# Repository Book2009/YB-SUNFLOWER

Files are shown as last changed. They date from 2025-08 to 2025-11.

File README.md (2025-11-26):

# Welcome to Team Sunflower's Repository 🌻✨
### ***We Are Team Sunflower From Thailand***

<p align="center">
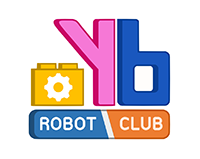
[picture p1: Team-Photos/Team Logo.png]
  
</p>

<p align="center">
  By Yothinburana School
</p>

---

# Content

`3DModels` – This folder includes the 3D design files of the vehicle. These files show the mechanical structure, dimensions, and how each part fits together.

`FlowChart` – This folder contains flowcharts that illustrate the robot’s control logic and how it processes sensor inputs during missions.

`Others` – This folder includes supporting materials such as the work schedule, and robot assembly GIFs.

`Program` – This folder includes all source codes used in the WRO 2025 Future Engineers category.

`Robot-Photos` – This folder contains photos of the vehicle from multiple perspectives.

`Schemes` – This folder contains wiring and electrical schematic diagrams. These diagrams show all components in the robot and how they are connected together.

`Team-Photos` – This folder includes photos of the team participating in the WRO 2025 Future Engineers Category.

`Videos` – This folder contains YouTube links that demonstrate how the robot operates to complete both missions.

`Readme` – This README contains 3 parts:
  - [About Us](#part-1-about-us)
  - [Mechanical Design](#part-2-mechanical-design)
  - [Obstacle Management](#part-3-obstacle-management)

---

# **Part 1: About Us**

## **This is our team.**
Our team name, **Sunflower**, carries a meaningful story. In Thai, the word “Sunflower” means *ดอกทานตะวัน*, which is directly connected to the name of one of our seniors. Since 2023, he has inspired us to join the Future Engineers competition—always supporting us and giving guidance from outside the team. To honor the role he played in motivating us, we included **“Sunflower”** in our team name.

This year is even more special, because in the national competition round, he was finally able to compete together with us as part of the team. Unfortunately, he is unable to join the international round of the competition.

<hr>

### **Team History**
We are **Sunflower**, a team from Bangkok, Thailand. We are part of the **YB-Robot Club** from Yothinburana School, with our mentor **Punnapon Tanasnitikul**.  
Our club website: https://ybrobot.club/

The club was established in 2009 under the original name **“YB Dream Team.”** Last year, we also participated in **WRO 2024**, which took place in Türkiye.

`2010 — First International Round Achievement`  
Our first time competing in the WRO international round, where our team achieved **3rd place (Second Runner-Up)**.  
<p align="center">
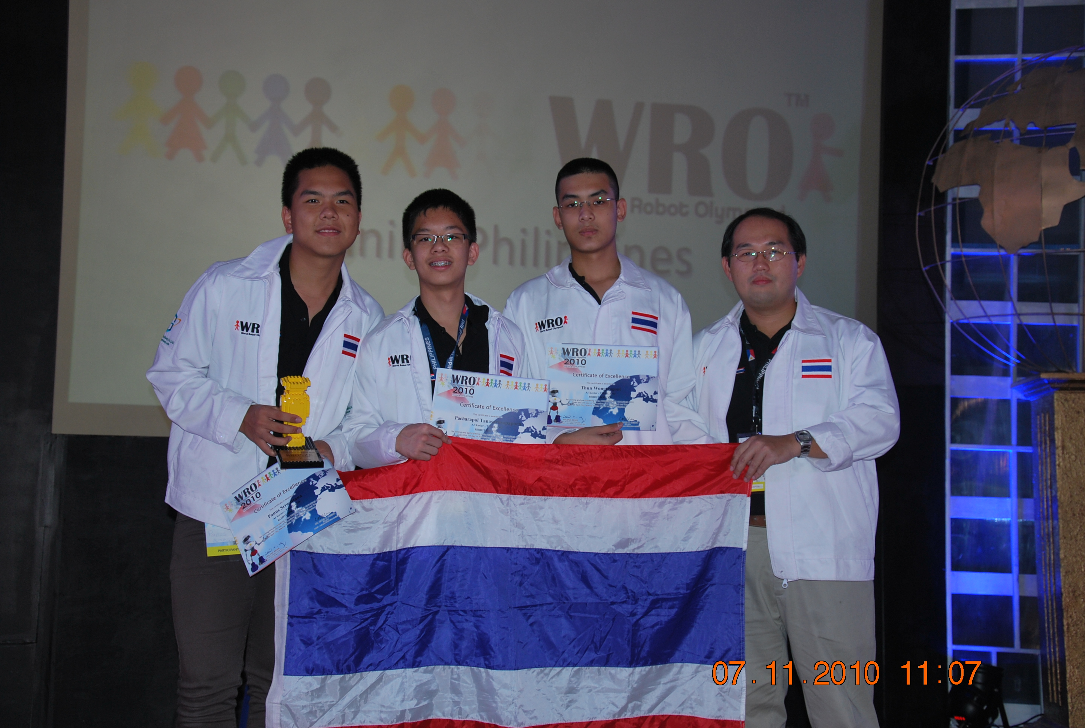
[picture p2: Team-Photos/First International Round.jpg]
  
</p>

`2011 — Second International Round Achievement`  
In our second participation in the WRO international round, our team won **1st place (Champion)**.  
<p align="center">
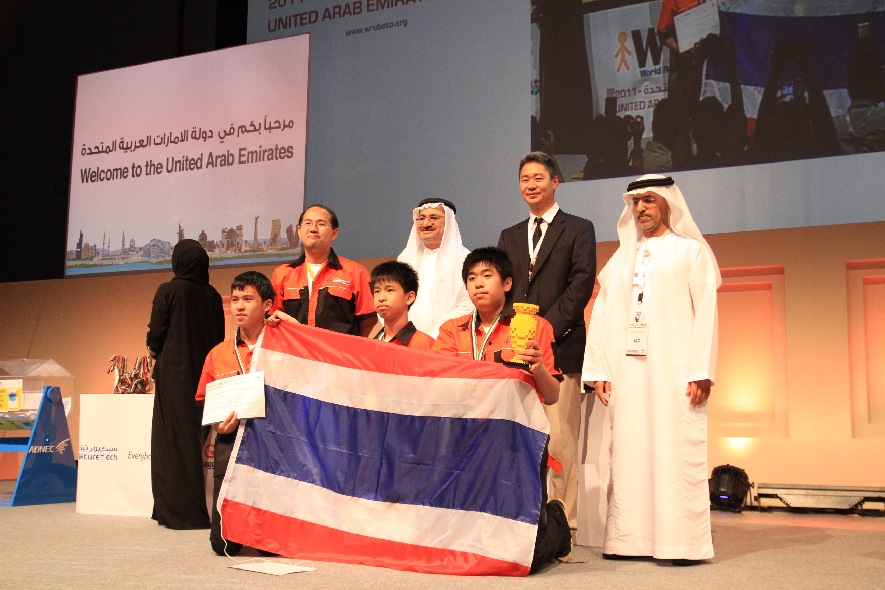
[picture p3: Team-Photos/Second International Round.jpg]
  
</p>

`Latest International Round Result`  
Among our many years of participation, the most recent highlighted result is from **2024**, where we placed **13th** in the international round.  
<p align="center">
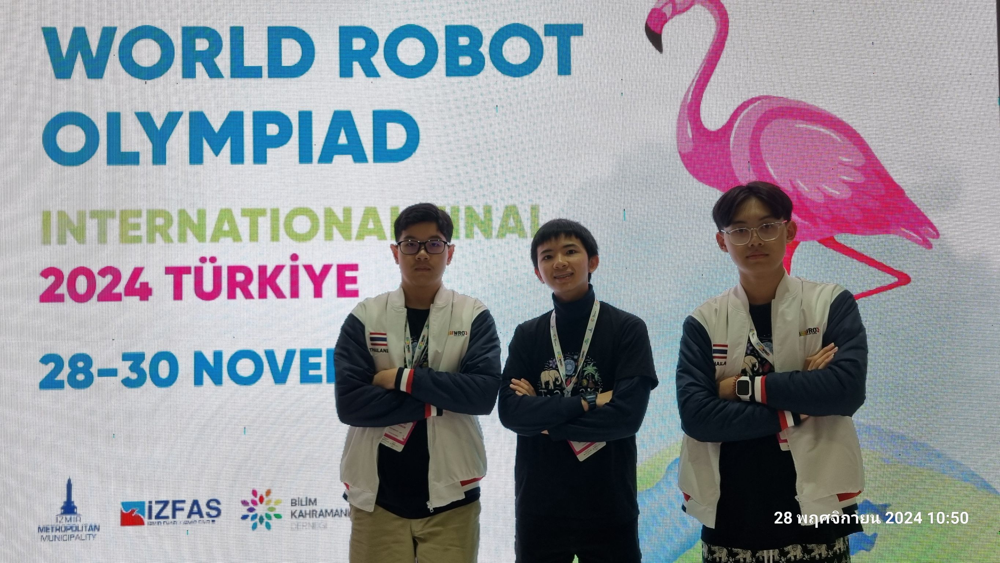
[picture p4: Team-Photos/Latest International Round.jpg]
  
</p>

Currently in 2025, we are part of the **YB Robot Team**. Our senior helped bring this team name to global recognition, and we aim to continue the legacy and make them proud.

<hr>

### **Our Team**
Our team consists of two close friends, **Thanyawut Krittikanon** and **Pawit Nateenantasawasd**. We have known each other since 2021 and formed a strong bond through years of working together in our school’s robotics club. Throughout high school, we joined many robotics competitions, shared knowledge, and improved our skills side by side. These shared experiences have shaped how well we collaborate today.

Over the past two years, we joined the **Future Engineers** category twice. Reaching the international round was already an honor, and although we finished in **8th** and **13th** place, those experiences taught us that enthusiasm alone is not enough—we needed stronger strategies, cleaner designs, and better execution.

This year, we return with greater confidence and far more experience. We refined our workflow, strengthened our engineering approach, and fixed the mistakes from previous years. Coming back to this competition motivates us to do our best, and we aim to deliver results that make everyone proud.

<p align="center">
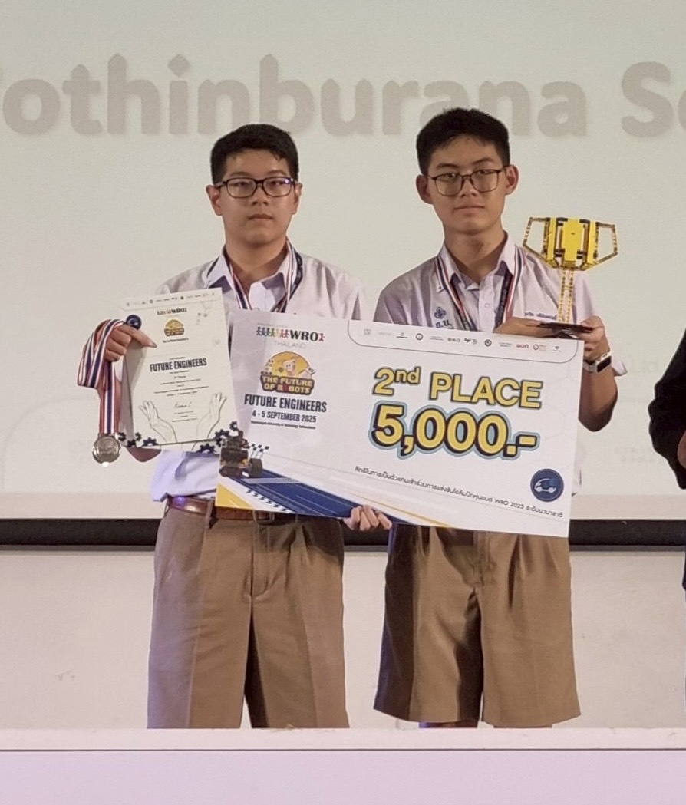
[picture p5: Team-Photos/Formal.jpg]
    
</p>
<hr>

There are two members on our team, each focused and dedicated to their responsibilities:

### **1. Thanyawut Krittikanon – Team Coordinator, Robot Designer & Document Designer**
<p align="center">
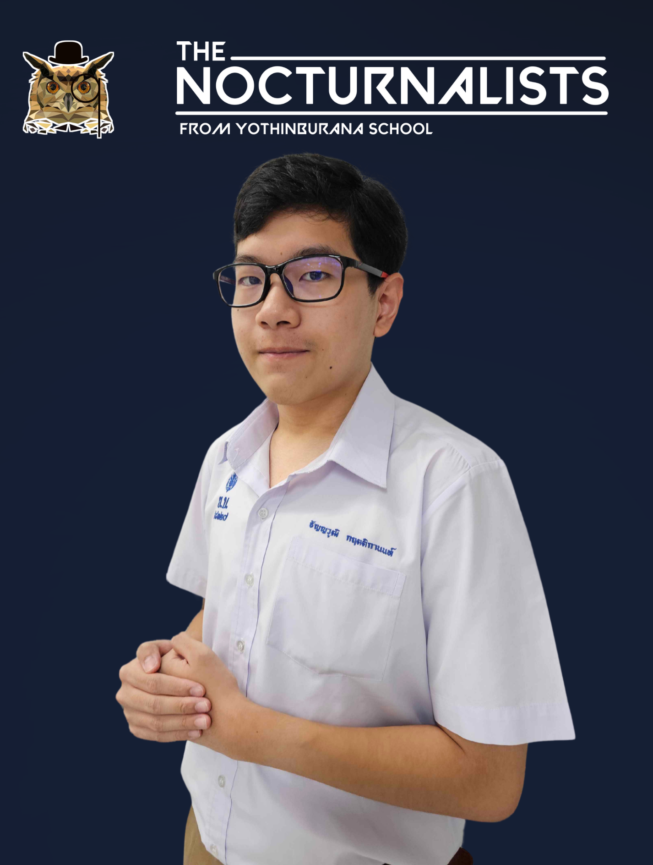
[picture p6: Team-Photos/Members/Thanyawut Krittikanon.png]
    
</p>

Thanyawut is responsible for team coordination, robot design, and documentation. His background in both robotics and programming helps him organize the team’s workflow and ensure that every process is clearly recorded and accurately presented.  

As the robot designer, he works on mechanical concepts and 3D modeling, turning ideas into practical and efficient designs. As the document designer, he structures the reports, diagrams, and technical explanations, ensuring that all information is clear, professional, and aligned with the competition requirements.

His creativity, attention to detail, and ability to combine engineering with presentation make him a key part of the team’s success.

---

### **2. Pawit Nateenantasawasd – Programmer**
<p align="center">
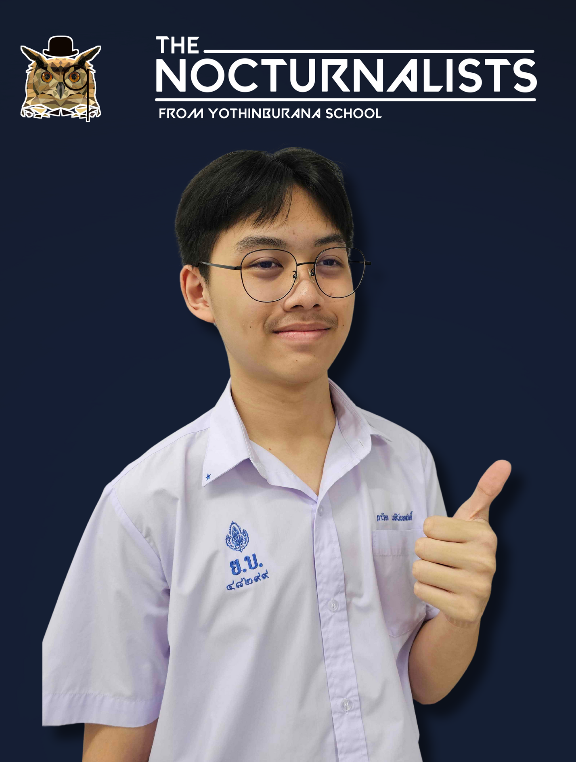
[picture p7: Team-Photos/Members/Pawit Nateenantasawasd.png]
    
</p>

Pawit is our lead programmer, specializing in languages such as **C++, C, Python, MicroPython, and HTML**.  
Quiet and focused, he excels at solving complex programming challenges with precision. His ability to stay concentrated allows him to implement highly detailed control logic and ensure that our robot operates smoothly and reliably. His dedication plays a key role in keeping the entire system functioning.

<hr>

### **Our Vision and Goal**

We aim to create a robot that operates similarly to a self-driving car, with the long-term dream of integrating our technology into real vehicles. This competition is an important step toward our future goals of contributing to our country and developing innovative solutions.  

Through participating in this competition, we have gained valuable skills such as collaboration, creativity, and forward thinking. We also hoped to meet new friends and exchange knowledge with teams from around the world.  

Furthermore, we plan to use the experience we gain from this tournament to improve ourselves and to guide and mentor our juniors at school, helping them grow just as we have.

<hr>

# **Part 2: MECHANICAL DESIGN**

## Robot Design Overview



The robot is primarily composed of custom 3D-printed components, forming a lightweight yet durable structure for all major systems. Each part is designed to fit its specific purpose and connects cleanly with others, creating a modular framework that can be easily upgraded or adjusted as our design evolves.

The overall layout supports the placement of motors, electronics, the battery, and key sensors while maintaining neat cable routing and good airflow. With the flexibility of 3D printing, we optimized the internal spacing, balance, and part placement to improve stability and functionality.

To ensure accurate obstacle detection, the LiDAR sensor is mounted in an unobstructed position (below 10 cm from the ground), giving it a clear field of view throughout the missions. This approach minimizes weight, simplifies assembly, and allows for quick replacement or upgrading of components.

[All 3D-printable models can be found here.](https://github.com/Book2009/YB-SUNFLOWER/tree/main/3DModels)

<hr>

### Main Base

<table align="center">
  <tr>
    <td align="center">
      
      <p><a href="https://github.com/Book2009/YB-SUNFLOWER/blob/main/3DModels/Main%20Base.stl" target="_blank">Click here to view the 3D model.</a></p>
    </td>
  </tr>
</table>

The Main Base serves as the robot’s primary structural layer. The Raspberry Pi 5 is mounted on this level to keep the board low, since an extension board sits on top of it; this position prevents unnecessary height, simplifies cable routing, and avoids blocking the camera’s field of view.

This layer provides mounting positions for the **Servo Bracket** and **Motor Mount**, which hold the steering servo and the motors with the differential gear mechanism. These mounting locations are centered to maintain proper alignment and balanced weight distribution. 

The Main Base also includes dedicated connection points for attaching the next structural layer, allowing the upper components to stack securely. 

<hr>

### Support Base 1

<table align="center">
  <tr>
    <td align="center">
        

  <p><a href="https://github.com/Book2009/YB-SUNFLOWER/blob/main/3DModels/Support%20Base%201.stl" target="_blank">Click here to view 3D model.</a></p>
  </tr>
</table>

Support Base 1 is the structural layer positioned above the Main Base. It provides mounting locations for the gyro sensor and the Lidar Mount, forming the platform where these components are securely attached. The rear section includes a recessed cutout that allows the power cable to pass through to the Raspberry Pi 5 without interference.

This part also features countersunk mounting holes, preventing the screw heads or nuts from protruding. This ensures that the wiring and the steering mechanism beneath the layer have sufficient clearance and do not come into contact with any hardware. Support Base 1 establishes a clean separation between the lower mechanical systems and the upper sensing components.

<hr>

### Support Base 2.1

<table align="center">
  <tr>
    <td align="center">
      

  <p><a href="https://github.com/Book2009/YB-SUNFLOWER/blob/main/3DModels/Support%20Base%202.1.stl" target="_blank">Click here to view 3D model.</a></p>
  </tr>
</table>

Support Base 2.1 is an upper structural layer used to mount the motor driver, touch sensor, and step-down module. The touch sensor and step-down are installed on angled surfaces, allowing the sensor to remain easily accessible even after **Support Base 2.2** is mounted above this layer, while also preventing the solder joints of the step-down module from contacting the printed part.

The angled geometry also improves printability and durability, as fully vertical mounts would be harder to print and more prone to breaking. A cable-routing slot is integrated to organize power wires and keep them clear of surrounding components. The part also includes mounting holes designed specifically for attaching the next structural layer.

This layer provides an efficient layout for key electronic modules while forming the connection point for the robot’s multi-layer assembly.

<hr>

### Support Base 2.2

<table align="center">
  <tr>
    <td align="center">
      

  <p><a href="https://github.com/Book2009/YB-SUNFLOWER/blob/main/3DModels/Support%20Base%202.2.stl" target="_blank">Click here to view 3D model.</a></p>
  </tr>
</table>

Support Base 2.2 is the structural layer installed above Support Base 2.1. It provides mounting locations for the step-down module that supplies power to the motor driver, as well as attachment points for the camera positioning mechanism, the camera shield plate, and the switch box.

The central recessed opening is designed specifically to allow the step-down module to sit lower in the structure, preventing its solder joints from contacting the printed surface and ensuring safe electrical clearance. The surrounding frame maintains rigidity while keeping all mounting points properly aligned with the lower layer.

This layer organizes several functional electronic and camera-related components while maintaining secure integration within the robot’s multi-layer mechanical structure.

<hr>

### Camera Shield Plate

<table align="center">
  <tr>
    <td align="center">
        

  <p><a href="https://github.com/Book2009/YB-SUNFLOWER/blob/main/3DModels/Camera%20Shield%20Plate.stl" target="_blank">Click here to view 3D model.</a></p>
  </tr>
</table>

The Camera Shield Plate is designed to prevent internal wires and electronic components from entering the camera’s field of view. Although software cropping can remove unwanted areas, this physical shield provides additional reliability—especially important when competing internationally, where lighting conditions and arena environments may differ from our testing setup. Since a 3D printer cannot be brought to the competition venue, the shield serves as a precaution against unexpected visual obstructions.

The plate is mounted using shared screw points with the lower support layers, forming an integrated structure. Its hood-like geometry blocks the camera’s downward and forward viewing angles, while the recessed underside creates extra clearance for the components beneath it, ensuring the shield sits correctly without interfering with wiring or modules.

<hr>

### Camera Positioning Mechanism

<p align="center">

</p>

<table align="center">
  <tr>
    <td align="center">
      Left
      <p><details>
  <summary>Camera Height Adjustment Link</summary>

  <p><a href="https://github.com/Book2009/YB-SUNFLOWER/blob/main/3DModels/Camera%20Height%20Adjustment%20Link.stl" target="_blank">Click here to view 3D model.</a></p>

</details></p>
    </td>
    <td align="center">
      Center
      <p><details>
  <summary>Angle Adjustment Link</summary>

  <p><a href="https://github.com/Book2009/YB-SUNFLOWER/blob/main/3DModels/Angle%20Adjustment%20Link.stl" target="_blank">Click here to view 3D model.</a></p>

</details></p>
    </td>
 <td align="center">
      Right
      <p><details>
  <summary>Camera Adjustment Column</summary>

  <p><a href="https://github.com/Book2009/YB-SUNFLOWER/blob/main/3DModels/Camera%20Adjustment%20Column.stl" target="_blank">Click here to view 3D model.</a></p>

</details></p>
    </td>
  </tr>
</table>

The Camera Positioning Mechanism is designed to provide adjustable camera height and angle, allowing the camera to be tuned for varying lighting conditions or different field environments during competition. This adjustability ensures the robot can adapt even when the lighting or arena setup in an international venue differs from our testing conditions.

The mechanism consists of three main components: the Camera Adjustment Column, the Height Adjustment Link, and the Angle Adjustment Link. The vertical slots in the column allow the camera to be raised or lowered, while the pivoting links enable precise angle adjustment. Together, these components form a compact and stable assembly that maintains the camera’s alignment while offering flexible configuration options.

This mechanism allows rapid on-site adjustments without requiring redesign or reprinting of parts.

<hr>

### Servo Bracket

<table align="center">
  <tr>
    <td align="center">
       

  <p><a href="https://github.com/Book2009/YB-SUNFLOWER/blob/main/3DModels/Servo%20Bracket.stl" target="_blank">Click here to view 3D model.</a></p>
  </tr>
</table>

The Servo Bracket is designed to mount a LEGO-compatible steering servo, which normally attaches using Technic pins instead of screws. To support this, the bracket includes integrated cylindrical pegs that function like Technic pins, allowing the servo to snap and lock securely into place.

Its U-shaped structure with side mounting plates provides stability and proper alignment when attached to the Main Base. The geometry positions the servo at the correct height and orientation for the steering mechanism while remaining lightweight and easy to print.

This design enables the LEGO-style servo to integrate seamlessly with the custom 3D-printed chassis.

<hr>

### Ultrasonic Sensor Mount

<table align="center">
  <tr>
    <td align="center">
      

  <p><a href="https://github.com/Book2009/YB-SUNFLOWER/blob/main/3DModels/Ultrasonic%20Sensor%20Mount.stl" target="_blank">Click here to view 3D model.</a></p>
  </tr>
</table>

The Ultrasonic Sensor Mount positions the sensor in a fixed forward-facing orientation. It is attached using the same screws that secure the rear side of the motor driver, allowing the mount to be installed without additional fasteners. Its slim, elongated shape provides the required spacing and keeps the sensor aligned and stable within the chassis.

<hr>

### Lidar Mount

<table align="center">
  <tr>
    <td align="center">
        

  <p><a href="https://github.com/Book2009/YB-SUNFLOWER/blob/main/3DModels/Lidar%20Mount.stl" target="_blank">Click here to view 3D model.</a></p>
  </tr>
</table>

The Lidar Mount holds the LiDAR sensor in its optimal position and is shaped with a recessed center area, allowing it to sit directly above the gyro module without interference. The mounting tabs on both sides secure the plate to the support structure, while the rounded top surface provides a stable platform for the LiDAR to operate with a clear field of view.

<hr>

### Motor Mount

<table align="center">
  <tr>
    <td align="center">
        

  <p><a href="https://github.com/Book2009/YB-SUNFLOWER/blob/main/3DModels/Motor%20Mount.stl" target="_blank">Click here to view 3D model.</a></p>
  </tr>
</table>

The Motor Mount is the only chassis component not produced with a 3D printer. It is made from steel to provide exceptional strength and rigidity for securing the motors. The mount includes threaded holes, allowing screws to be fastened directly without the need for nuts, making the part both compact and easy to assemble.

Although steel is heavier than plastic, the mount’s small size keeps the weight minimal. A plastic version would need to be larger and reinforced to match the required strength, resulting in no real weight advantage. Using steel ensures long-term durability, high resistance to mechanical stress, and a stable foundation for the motor system.

<p align="center">


<hr>

### Gear Adapter

<table align="center">
  <tr>
    <td align="center">
      

  <p><a href="https://github.com/Book2009/YB-SUNFLOWER/blob/main/3DModels/Gear%20Adapter.stl" target="_blank">Click here to view 3D model.</a></p>
  </tr>
</table>

The gear adapter is a custom-designed component that interfaces the GM25 motor with LEGO differential gears. Since the GM25 motor shaft cannot directly engage with LEGO gears, this adapter provides a secure and precise connection. The central bore is dimensioned for a tight press-fit onto the GM25 shaft to prevent slippage during operation, while two side holes accommodate LEGO Technic pins, allowing the adapter to lock seamlessly into the LEGO gear system.

This design enables a robust integration between a non-LEGO motor and LEGO drivetrain components, ensuring smooth, reliable, and efficient power transmission.

<p align="center">
   

<hr>

### Rear Wheel Bearing Mount
<p align="center">

</p>

<table align="center">
  <tr>
    <td align="center">
      Left
      <p><details>
  <summary>Right Bearing Mount</summary>

  <p><a href="https://github.com/Book2009/YB-SUNFLOWER/blob/main/3DModels/Right%20Bearing%20Mount.stl" target="_blank">Click here to view 3D model.</a></p>

</details></p>
    </td>
    <td align="center">
      Center
      <p><details>
  <summary>Middle Bearing Mount</summary>

  <p><a href="https://github.com/Book2009/YB-SUNFLOWER/blob/main/3DModels/Middle%20Bearing%20Mount.stl" target="_blank">Click here to view 3D model.</a></p>

</details></p>
    </td>
 <td align="center">
      Right
      <p><details>
  <summary>Left Bearing Mount</summary>

  <p><a href="https://github.com/Book2009/YB-SUNFLOWER/blob/main/3DModels/Left%20Bearing%20Mount.stl" target="_blank">Click here to view 3D model.</a></p>

</details></p>
    </td>
  </tr>
</table>

The Rear Wheel Bearing Mount is designed to hold standard ball bearings that support the differential output shaft. The inner race of the bearing interfaces with the shaft through a custom sleeve, allowing smooth and low-friction rotation, while the outer race is securely fixed within the mount. This configuration keeps the rear axle properly aligned, prevents bending under load, and avoids the friction that would occur if the shaft were to rotate directly against 3D-printed surfaces.

The bearing mounts are split into left, middle, and right sections to match the spacing and geometry of the drivetrain, functioning similarly to a pillow block bearing while fitting the robot’s compact chassis layout.

<p align="center">


<hr>

### Axle Sleeve Adapter

<p align="center">

</p>

<table align="center">
  <tr>
    <td align="center">
      Left
      <p><details>
  <summary>Right Axle Sleeve Adapter(For Rear Wheel)</summary>

  <p><a href="https://github.com/Book2009/YB-SUNFLOWER/blob/main/3DModels/Right%20Axle%20Sleeve%20Adapter(For%20Rear%20Wheel).stl" target="_blank">Click here to view 3D model.</a></p>

</details></p>
    </td>
    <td align="center">
      Right
      <p><details>
  <summary>Left Axle Sleeve Adapter(For Rear Wheel)</summary>

  <p><a href="https://github.com/Book2009/YB-SUNFLOWER/blob/main/3DModels/Left%20Axle%20Sleeve%20Adapter(For%20Rear%20Wheel).stl" target="_blank">Click here to view 3D model.</a></p>

</details></p>
    </td>
  </tr>
</table>

The Axle Sleeve Adapter is designed to interface the LEGO cross axle with the inner bore of the bearing used in the Rear Wheel Bearing Mount. The cross axle, which transmits rotational power from the differential gear to the rear wheels, does not match the circular geometry of the The Axle Sleeve Adapter is designed to interface the LEGO cross axle with the circular inner bore of the bearing used in the Rear Wheel Bearing Mount. Because the LEGO cross axle does not match the round geometry of the bearing, the adapter includes a cross-shaped internal profile that fits the axle tightly, while the outer surface is machined as a precise cylinder sized for the bearing.

This sleeve prevents the axle from rubbing against printed surfaces, allowing the rear shaft to rotate smoothly through the bearing while remaining properly aligned. By providing a secure and accurate connection between the LEGO drivetrain and the bearing-supported structure, the Axle Sleeve Adapter improves durability, reduces friction, and increases the efficiency of the rear-wheel power transmission system.

<p align="center">


<hr>

### Steering Module
<p align="center">

</p>

<table align="center">
  <tr>
    <td align="center">
      Left
      <p><details>
  <summary>Right Steering Arm</summary>

  <p><a href="https://github.com/Book2009/YB-SUNFLOWER/blob/main/3DModels/Right%20Steering%20Arm.stl" target="_blank">Click here to view 3D model.</a></p>

</details></p>
    </td>
    <td align="center">
      Center
      <p><details>
  <summary>Top Steering Mount</summary>

  <p><a href="https://github.com/Book2009/YB-SUNFLOWER/blob/main/3DModels/Top%20Steering%20Mount.stl" target="_blank">Click here to view 3D model.</a></p>

</details></p>
    </td>
 <td align="center">
      Right
      <p><details>
  <summary>Right Steering Arm</summary>

  <p><a href="https://github.com/Book2009/YB-SUNFLOWER/blob/main/3DModels/Right%20Steering%20Arm.stl" target="_blank">Click here to view 3D model.</a></p>

</details></p>
    </td>
  </tr>
</table>

<table align="center">
  <tr>
    <td align="center">
      Left
      <p><details>
  <summary>Axle Sleeve Adapter(For Front Wheel) x2</summary>

  <p><a href="https://github.com/Book2009/YB-SUNFLOWER/blob/main/3DModels/Axle%20Sleeve%20Adapter(For%20Front%20Wheel)%20x2.stl" target="_blank">Click here to view 3D model.</a></p>

</details></p>
    </td>
    <td align="center">
      Center
      <p><details>
  <summary>Bottom Steering Mount</summary>

  <p><a href="https://github.com/Book2009/YB-SUNFLOWER/blob/main/3DModels/Bottom%20Steering%20Mount.stl" target="_blank">Click here to view 3D model.</a></p>

</details></p>
    </td>
 <td align="center">
      Right
      <p><details>
  <summary>Steering Linkage Arm</summary>

  <p><a href="https://github.com/Book2009/YB-SUNFLOWER/blob/main/3DModels/Steering%20Linkage%20Arm.stl" target="_blank">Click here to view 3D model.</a></p>

</details></p>
    </td>
  </tr>
</table>

- #### **Steering Linkage Arm**
Connected directly to the steering servo, this arm converts the servo’s rotational output into a push–pull motion. This motion is transferred to both steering arms, allowing the front wheels to change direction together. The linkage is dimensioned to provide smooth and precise steering response.

- #### **Top Steering Mount**
The top bracket that holds the steering assembly together. It stabilizes the upper side of the steering arms and ensures they remain aligned during rotation. Together with the bottom mount, it keeps the module rigid while still allowing the arms to pivot freely.

- #### **Bottom Steering Mount**
The lower structural plate of the steering module. Aside from supporting and aligning the steering arms from below, it also includes a dedicated mounting position for the light sensor. This placement allows the sensor to stay close to the ground for accurate line detection while being protected inside the steering assembly.

- #### **Steering Arm (Left & Right)**
These arms connect directly to each front wheel and convert the push–pull input from the linkage into wheel rotation. Each arm includes a dedicated cylindrical pivot point that fits a metal standoff tube, allowing the arm to rotate smoothly with minimal friction.
The geometry is angled inward to approximate Ackermann steering, ensuring correct wheel angles during turns for improved cornering stability and reduced tire scrub.

<p align="center">


The metal tube remains fixed between the Main Base and Support Base 1, acting as a pivot shaft, while the steering arm rotates around it smoothly.

<p align="center">


- #### **Axle Sleeve Adapter(For Front Wheel) x2**
These adapters allow the LEGO cross axle of the front wheels to interface with the circular inner diameter of the bearings mounted inside the steering arms. The inner profile matches the LEGO axle, while the outer profile fits tightly into the bearing. This ensures smooth bearing rotation and stable wheel alignment—just like the system used for the rear wheels.

<hr>

### Bare Robot Frame

- #### **This image shows the robot’s bare frame, illustrating what the structure looks like without any components installed.**

<p align="center">


## Components

- #### **3D Printer**: Bambu Lab X1 Carbon by Bambu Lab
<image src="https://github.com/Book2009/FE-NOC/blob/main/Robot-Photos/Robot%20Parts/3D/3D%20Printer.png" width = "400">
  
The reasons that we use Bambu Lab X1-Carbon 3D printer because this printer is a high-performance 3D printer designed for precision and efficiency. It is equipped with advanced technology and features, making it suitable for professional use as well as hobbyist projects that require high-quality prints.

##### General Specifications

| Specification | Value |
|---|---|
| Build Volume | 256 × 256 × 256 mm³* |
| Nozzle | 0.4 mm Hardened Steel Included |
| Hotend | All-Metal |
| Max Hot End Temperature | 300 ℃ |
| Filament Diameter | 1.75 mm |
| Supported Filament | PLA, PETG, TPU, ABS, ASA, PVA, PET |
| Ideal for | PA, PC, Carbon/Glass Fiber Reinforced Polymer |

##### Build Plate Specifications

| Specification | Value |
|---|---|
| Build Plate Surface | Bambu Textured PEI Plate or Bambu Cool Plate (Pre-installed, Random, Both compatible with Micro Lidar) |
| Max Build Plate Temperature | 110℃@220V, 120℃@110V |

##### Tool Head Specifications

| Specification | Value |
|---|---|
| Max Speed | 500 mm/s |
| Max Acceleration | 20 m/s² |

##### Physical Dimensions

| Specification | Value |
|---|---|
| X1C Dimensions | 389 × 389 × 457 mm³ |
| Package Size (X1C) | 480 × 480 × 535 mm³ |
| Net Weight (X1C) | 14.13 kg |
| Gross Weight (X1C) | 18 kg |
| Package Size (X1C Combo) | 480 × 480 × 590 mm³ |
| Gross Weight (X1C Combo, AMS included) | 22.3 kg |

##### Electrical Requirements

| Specification | Value |
|---|---|
| Voltage | 100-240 VAC |
| Frequency | 50/60 Hz |
| Power Consumption | 1000W@220V, 350W@110V |

<hr>

- #### **Filament** : Acrylonitrile Butadiene Styrene or simply known as ***ABS***
<image src="https://github.com/Book2009/FE-NOC/blob/main/Robot-Photos/Robot%20Parts/3D/ABS%20Filament.png" width = "400">
  
ABS (Acrylonitrile Butadiene Styrene) was selected as the primary material for the robot’s structural components due to its balanced mechanical and thermal properties. Unlike more brittle plastics, ABS provides a unique combination of rigidity and impact resistance, which allows the parts to endure operational stresses without cracking. Its slight flexibility enables the structures to absorb shocks and vibrations while maintaining dimensional stability. Moreover, ABS retains its form and strength across a wide range of operating temperatures, ensuring reliable performance under varying environmental conditions. These properties make ABS particularly suitable for 3D-printed parts, where durability, accuracy, and stability are essential for assembling complex robotic systems.

<hr><br>

### Movement Parts

- #### **Driving motor** : Chihai 25-370K DC 12V (Gear Ratio 1:20)™.
<image src="https://github.com/ThanyawutII/Test2/blob/main/Hf0a6048f4d30411fbd880a854753fdeaF-removebg-preview.png" width = "400"> <image src="https://github.com/ThanyawutII/Test2/blob/main/DeWatermark.ai_1756699222216.jpg" width = "500">

The Chihai 25-370K DC 12V gear motor with a 1:20 reduction ratio was selected as the drive motor for the robot because it offers an effective balance between speed and torque. The high output speed provided by this configuration allows the robot to achieve competitive ground velocity, while the available torque remains sufficient to drive the system reliably under load. The motor operates efficiently within the limits of the designed power system, and its compact size makes it easy to integrate into the chassis without adding unnecessary weight. In addition, the motor is well suited for use with the LEGO differential gear, ensuring smooth power transmission and responsive handling. Overall, this motor was chosen as the optimal trade-off to provide both performance and stability for competition tasks.

##### Electrical Specifications

| Specification | Value |
|---|---|
| Voltage | 12V DC |

##### Mechanical Specifications

| Specification | Value |
|---|---|
| RATIO | 1: 20  |
| no-load current(mA) | ≤600 |
| no-load speed(rpm) | 980  |
| rated torque(Kg.cm) | 2.3 |
| rated torque(N.m) | 0.21  |
| rated speed (rpm) | 780  |
| rated current (A) | ≤2.7 |
| stall current (A) | ≤16.0  |
| length of gearbox(L) | 19.0 |

<hr>

- #### **Motor Drive Gear** : LEGO Technic Gear 28 Tooth
<image src = "https://github.com/ThanyawutII/Test/blob/main/maxresdefault-removebg-preview.png" width = "250">

The 28-tooth motor drive gear was selected because it provides a perfect 1:1 connection with the 28-tooth differential gear, ensuring smooth and direct power transfer from the motor to the drivetrain. By using gears with equal tooth counts, the system avoids unnecessary changes in torque or speed at this stage, maintaining the rated output characteristics of the motor. This choice simplifies the design, reduces potential misalignment, and ensures high efficiency by minimizing frictional losses. Additionally, the 28-tooth gear is widely compatible with LEGO Technic components, making it reliable and easy to integrate with the differential assembly. Overall, this gear was chosen to achieve stable, efficient, and precise transmission between the motor and the differential system.

<hr>

- #### **Differential Gear** : LEGO Technic Differential Gear (28 teeth)
<image src = "https://github.com/ThanyawutII/Test2/blob/main/80696-removebg-preview.png" width = "300"> <image src = "https://github.com/ThanyawutII/Test-2/blob/main/different.jpg" width = "400">

The LEGO Technic Differential Gear (28 teeth) is a compact gear unit designed to distribute power from a single input to two output shafts, allowing each wheel to rotate at different speeds while still receiving balanced torque. Inside the housing, bevel gears transmit motion from the input gear to the cross axles, ensuring smooth operation during turns. This mechanism replicates the function of a real automotive differential: when the robot moves straight, both wheels rotate together, but during cornering, the inner wheel slows down while the outer wheel speeds up, reducing slip and energy loss. Its 28-tooth outer gear integrates seamlessly with other LEGO gears, making it easy to combine with custom adapters and non-LEGO components. By using this differential, the drivetrain achieves smoother cornering, improved maneuverability, and more realistic vehicle dynamics essential for competitive robotics.

<hr>

- #### **Driving Motor with Differential Gear**
<image src="https://github.com/ThanyawutII/Test2/blob/main/Screenshot_2025-09-01_124212-removebg-preview.png" width = "500">

After presenting the information and the reasons for selecting the motor and the differential gear, the next crucial step is to understand the outcomes resulting from the connection of these two components. This analysis aims to determine the speed and torque that the system can deliver, which are key factors in optimizing and enhancing the system's performance. Below are the calculation methods and the results derived from our analysis

#### **Step 1: Calculate the gear ratio**
<p>The gear ratio is determined by the ratio of the number of teeth on the input and output gears:</p>
<div class="equation">
    Gear Ratio = <sup>Number of teeth on input gear</sup> / <sub>Number of teeth on output gear</sub> = <sup>28</sup> / <sub>28</sub> = 1.0
</div>

#### **Step 2: Calculate output RPM**
<p>The output RPM is calculated based on the motor's rated speed and the gear ratio:</p>
<div class="equation">
    Output RPM = Input RPM × Gear Ratio = 780 × 1.0 = 780 RPM
</div>
<p>(Using the no-load speed would give approximately 980 RPM.)</p>

#### **Step 3: Calculate output torque**
<p>The torque decreases inversely proportional to the gear ratio. With a 1:1 ratio, the torque remains unchanged from the motor:</p>
<div class="equation">
    Output Torque = <sup>Input Torque</sup> / <sub>Gear Ratio</sub> = <sup>0.21</sup> / <sub>1.0</sub> = 0.21 N·m
</div>
<p>Since the differential splits torque between two wheels, each wheel receives approximately half:</p>
<div class="equation">
    Per-wheel Torque ≈ 0.105 N·m
</div>

#### **Final Results:**
<ul>
    <li><strong>Output RPM @ differential</strong>: ~780 RPM (rated), ~980 RPM (no-load)</li>
    <li><strong>Output Torque @ differential</strong>: ~0.21 N·m (≈ 2.3 kg·cm)</li>
    <li><strong>Per-wheel Torque</strong>: ~0.105 N·m (≈ 1.05 kg·cm)</li>
</ul>

<hr>

- #### **Servo** : GEEKSERVO 2kg 360 Degrees Servo.
<image src="https://github.com/Book2009/FE-NOC/blob/main/Robot-Photos/Robot%20Parts/Movement/servo.png" width = "400">
We use this servo for steering the robot and employ an ultrasonic sensor for rotation. This servo is compatible with LEGO, making it easy and convenient to build the robot by just putting studs in the hole on the side. We like how you can connect two axles to the dual outputs on this servo so you can power two wheels or gears or mount the servo securely inside articulated limbs and other contraptions. Additionally, the gears inside these servos will 'slip' when the blocking load is too high instead of jamming, helping avoid damage to your servos and boards.

The wires are a standard servo pinout - 
-	Red - positive
-	Brown - negative
-	Yellow - data

##### Electrical Specifications

| Specification | Value |
|---|---|
| Working voltage | 3.3V~6V  |
| Rated voltage | 4.8V |
| Rated current | 200mA |
| Stall current | 700mA |
| Sliding current | 450mA |

<hr>

- #### **Wheel** : Lego Tire 43.2 x 22 ZR and Wheel 30.4mm D. x 20mm with No Pin Holes and Reinforced Rim
<image src = "https://github.com/ThanyawutII/Test/blob/main/Screenshot_2024-10-23_143240-removebg-preview.png" width = "200"> <image src = "https://github.com/ThanyawutII/Test/blob/main/56145-removebg-preview%20(1).png" width = "200">

There are many wheel options available, but this wheel was chosen primarily because of its optimal size for the drivetrain configuration. If the wheels are too small, the robot loses speed since the ground distance covered per rotation is reduced. On the other hand, if the wheels are too large, the robot becomes slower to accelerate, requires more torque to drive, and is harder to control precisely. By selecting a medium-sized wheel, the design achieves a good balance between speed and controllability. In combination with the chosen motor, this wheel size allows the robot to maintain a competitive ground speed while ensuring smooth handling and stable maneuverability during tasks.

<hr><br>

### Controller

- #### **Main Board** : Raspberry Pi 5 (8GB) from Raspberry Pi


The Raspberry Pi 5 (8GB) serves as the main processing unit of the robot. It functions like a high-performance mini computer, capable of handling advanced and computationally intensive tasks such as camera processing, LiDAR data analysis, SLAM, navigation algorithms, and real-time decision-making. Compared to previous generations, the Raspberry Pi 5 provides a major leap in CPU, GPU, and I/O performance, making it ideal for robotics applications that require fast data throughput and reliable multitasking.

We use this board because it delivers significantly higher processing power in the same compact form factor, while also providing improved interfaces for high-bandwidth devices such as multiple cameras, high-speed sensors, and NVMe storage.

| Specification | Value |
|---|---|
| **Main Board / SOC** | BCM2712 |
| **Processor** | Quad-core 64-bit ARM Cortex-A76, 2.4 GHz, with cryptography extensions, 512 KB L2 per core + 2 MB shared L3  |
| **Memory Options** | 1 GB, 2 GB, 4 GB, 8 GB LPDDR4X-4267 SDRAM |
| **Wireless** | Dual-band Wi-Fi (2.4 GHz & 5 GHz, 802.11ac), Bluetooth 5.0 / BLE |
| **Ethernet** | Gigabit Ethernet, with support for PoE+ via separate HAT |
| **USB Ports** | 2 × USB 3.0, 2 × USB 2.0 |
| **GPIO** | 40-pin header (fully backwards compatible) |
| **Display Output** | 2 × micro-HDMI (dual 4Kp60 with HDR) |
| **Camera Interface** | 2 × 4-lane MIPI CSI / DSI transceivers (i.e., supports two cameras or two displays) |
| **Audio/Video** | 4-pole stereo audio and composite video port |
| **Video Support** | H.265 (4kp60 decode), H.264 (1080p60 decode, 1080p30 encode) |
| **Graphics** | OpenGL ES 3.1, Vulkan 1.0 |
| **Storage** | Micro-SD card slot (supports high-speed SDR104) Raspberry Pi BD Also supports PCIe 2.0 x1 for NVMe SSD via HAT |
| **Power Input** | 5V DC via USB-C (min 3A), 5V DC via GPIO (min 3A), Power over Ethernet (PoE with HAT) |
| **Operating Temperature** | 0 – 50 °C ambient |

<hr>

### **Interface Board — IO Expansion HAT for Raspberry Pi (DFR0566)**


The IO Expansion HAT for Raspberry Pi (DFR0566) acts as the main interface layer between the Raspberry Pi and most of the robot’s low-level electronics. In our system, only the camera and LiDAR are connected directly to the Raspberry Pi; all other sensors and actuators—such as the light sensor, touch sensor, gyroscope, ultrasonic sensor, and motor driver control signals—are routed through this expansion board. It adds analog input capability, provides 5V-compatible I/O ports, and uses Gravity-style connectors to simplify wiring and reduce mistakes. By offloading sensor interfacing to this HAT, the Raspberry Pi can focus on high-level tasks like camera processing and mission logic, while the overall wiring becomes cleaner, safer, and easier to maintain during the competition.

| Specification | Value |
|---|---|
| Supported Platforms | Raspberry Pi 2B / 3B / 3B+ / 4B / Zero / Zero W / Pi 5 |
| I/O Ports | 24 (Gravity-compatible) |
| Analog Inputs | 6 (A0–A5, via ADS7830 ADC) |
| Communication to Pi | I²C |
| Output Voltage | 5V regulated |
| Power Input | From Pi header or external 5V |
| Port Type | Gravity 3-pin (VCC–GND–Signal) |
| Dimensions | 65 × 56 mm |

<hr>

### **Motor Driver — L298N**


The L298N motor driver is used to power our GM25 motors, which require a **12V supply**—a voltage far higher than what the Raspberry Pi or the IO Expansion HAT can handle. Since the Raspberry Pi operates at only **5V**, the motor power must be isolated to prevent damage. The L298N receives 12V directly from the battery and handles all high-current motor output, while the control signals (direction and PWM) are safely provided through the Expansion HAT. This separation protects the Raspberry Pi, ensures stable power delivery to the motors, and allows precise control of speed and direction during movement.

| Specification | Value |
|---|---|
| Motor Voltage | 5V–35V |
| Output Current | Up to 2A per channel |
| Power Dissipation | 25W (at 75°C) |
| Driver Structure | Dual H-bridge |
| Power Input | External power terminal |
| Output Ports | 2 motor channels (screw terminals) |
| Control Signals | TTL digital inputs + PWM |
| Operating Temperature | -25°C to 130°C |
| Board Size | 56 × 57 mm |

<hr><br>

### Power Management And Inspection
### **Camera — Raspberry Pi Night Vision Camera Module**


The Raspberry Pi Night Vision Camera Module is used as the main vision system of our robot. It connects directly to the Raspberry Pi through the MIPI-CSI interface, allowing high-speed image transmission for real-time processing. The built-in infrared capability ensures that the camera can maintain consistent brightness detection even under uneven lighting conditions, which is especially useful when competing abroad where lighting environments may differ from local testing. Its compact size and fixed-focus lens make it stable, lightweight, and easy to mount on our adjustable camera mechanism.

Thanks to its direct connection to the Raspberry Pi, the camera provides low-latency image data, enabling fast color detection, line tracking, and environmental inspection during autonomous operation.

| Specification | Value |
|---|---|
| Camera Type | Raspberry Pi Night Vision |
| Resolution | 5 MP |
| Sensor Format | 1/4 inch |
| Lens Type | Fixed focus |
| Infrared Capability | Yes (IR-sensitive) |
| Interface | MIPI CSI |
| PCB Size | 25 × 24 mm |
| Field of View | ~60° (depending on lens) |

<hr>

- #### **Lidar** : RPLiDAR C1
<image src="https://github.com/ThanyawutII/Test2/blob/main/Screenshot_2025-09-01_145336-removebg-preview.png" width = "400">
  
The RPLIDAR C1 was selected as the primary distance measurement sensor of the robot because it provides 360° scanning with a reliable detection range in a compact design. This makes it ideal for mapping the environment, detecting obstacles, and assisting in navigation during competition tasks. By connecting the LiDAR directly to the Raspberry Pi on the first layer, the system can process scan data in real time with minimal latency. The wide field of view ensures that the robot has continuous situational awareness, while the lightweight and low-power design makes it easy to integrate into the chassis without adding unnecessary load. Overall, the RPLIDAR C1 enables accurate environmental perception and enhances the robot’s ability to navigate efficiently and safely.

<p align="center">


| Specification | Value |
|---|---|
| Distance Range | White object: 0.05–12 m (70% reflection), Black object: 0.05–6 m (10% reflection) |
| Sample Rate | 5 kHz |
| Scanning Frequency | 8–12 Hz (10 Hz typical) |
| Angular Resolution | 0.72° (typical) |
| Scan Field Flatness | 0°–1.5° |
| Communication Interface | TTL UART |
| Communication Speed | 460800 bps |
| Accuracy | ±30 mm |
| Resolution | 15 mm |
| Degree of Protection | IP54 |
| Ambient Light Limit | 40000 lux |
| Weight | 110 g |
| Working Temperature Range | -10 ~ 40 °C |
| Storage Temperature Range | -20 ~ 60 °C |

<hr>

- #### **Ultrasonic sensor** : Gravity URM 09 ultrasonic distance sensor.
<image src="https://github.com/Book2009/FE-NOC/blob/main/Robot-Photos/Robot%20Parts/Power%20Management%20And%20Inspection/Ultrasonic.png" width = "400">
  
An Ultrasonic sensor is a device that can measure the distance to an object by using sound waves. It measures distance by sending out a sound wave at a specific frequency and listening for that sound wave to bounce back.

Since it is known that sound travels through air at about 344 m/s (1129 ft/s), you can take the time for the sound wave to return and multiply it by 344 meters (or 1129 feet) to find the total round-trip distance of the sound wave. Round-trip means that the sound wave traveled 2 times the distance to the object before it was detected by the sensor; it includes the 'trip' from the sonar sensor to the object AND the 'trip' from the object to the Ultrasonic sensor (after the sound wave bounced off the object). To find the distance to the object, simply divide the round-trip distance in half.

DFRobot URM09 is an ultrasonic sensor specially designed for fast ranging and obstacle avoidance applications. Its measuring frequency can reach up to 30Hz. The sensor adopts built-in temperature compensation and analog output. Meanwhile, it can provide accurate distance measurement within 500 cm. The sensor is compatible with Arduino, Raspberry Pi, or other main controllers.

<p align="center">
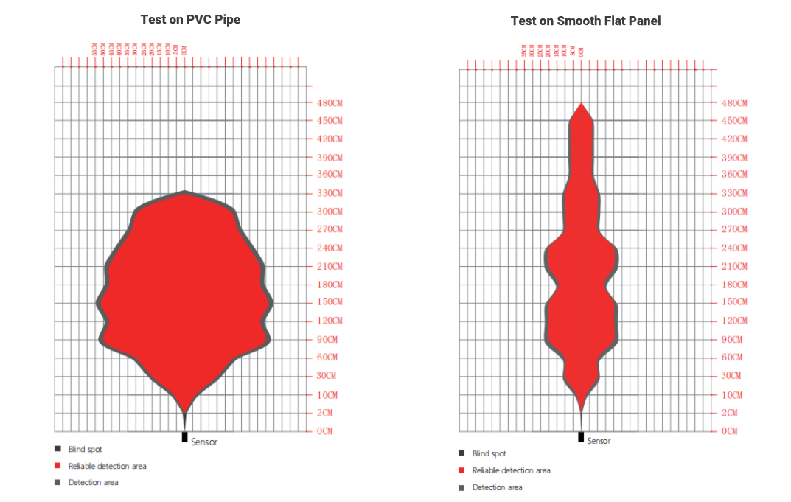
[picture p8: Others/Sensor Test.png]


<p align="center">
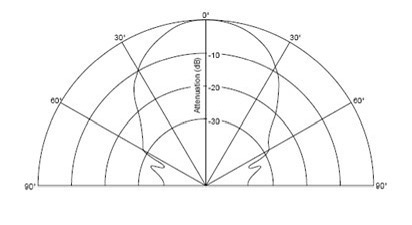
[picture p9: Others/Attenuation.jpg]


We use the Ultrasonic Sensor (SEN0307) to measure the distance between the robot and the walls. This sensor utilizes an analog voltage output and provides accurate distance measurements within the range of 2-500 cm, with a precision of 1 cm and an accuracy of ±1%. It is highly suitable for this competition and is compatible with boards that have 3.3V or 5V logic levels.

##### Electrical Specifications

| Specification | Value |
|---|---|
| Supply Voltage | 3.3~5.5V DC |
| Operating Current | 20mA |

##### Performance Specifications

| Specification | Value |
|---|---|
| Operating Temperature Range | -10°C to +70°C |
| Measurement Range | 2cm to 500cm (can be set) |
| Resolution | 1cm |
| Accuracy | 1% |
| Frequency | 50Hz Max |

<hr>

- #### **Light Sensor** : ZX-03B and ZX-03R By INEX

Light Sensor White

<image src = "https://github.com/ThanyawutII/Essent1/blob/main/Light%20Sensor%20White.png" width = "300">

Light Sensor Red

<image src = "https://github.com/ThanyawutII/Essent1/blob/main/Light%20Sensor%20Red.png" width = "300">

The color sensors play an important role in both rounds, as we use them for line detection. There are 2 lines with different colors in the corner of the race field, which is why we use 2 different colors of the color sensor, white and red. The white color sensor is used for detecting both colors, while the red color sensor is only used for the blue line.

<hr>

- #### **Gyro/Compass** :Gravity: 10 DOF IMU AHRS (BNO055 + BMP280)
<image src = "https://github.com/ThanyawutII/Test2/blob/main/Screenshot_2025-09-01_150533-removebg-preview.png" width = "400">

The Gravity: 10 DOF IMU AHRS (BNO055 + BMP280) was chosen as the gyroscope and compass module for this year’s design after replacing the ZX-IMU used previously, which suffered from significant drift and instability. The BNO055 integrates a 9-axis sensor with onboard sensor fusion, providing absolute orientation data without the need for complex external algorithms, while the BMP280 adds barometric pressure sensing for more accurate altitude estimation. This combination delivers highly stable and reliable motion tracking, minimizing drift over time and ensuring consistent heading information. With these improvements, the module provides precise orientation and environmental awareness, making it a robust upgrade that enhances both navigation accuracy and overall performance of the robot.

| Specification | Value |
|---|---|
| Operating Voltage | 3.3V ~ 5V DC |
| Operating Current | 5 mA |
| Interface | Gravity-I2C |
| BNO055 Accelerometer | ±2g / ±4g / ±8g / ±16g, LPF 1 kHz ~ <8 Hz, modes: normal, suspend, low power, standby, deep suspend |
| Accelerometer Interrupt | Motion-triggered interrupt-signal |
| BNO055 Gyroscope | ±125°/s ~ ±2000°/s, LPF 523 Hz ~ 12 Hz, modes: normal, fast power up, deep suspend, suspend, advanced power save |
| Gyroscope Interrupt | Motion-triggered interrupt-signal |
| BNO055 Geomagnetic Sensor | ±1300 µT (x-, y-axis), ±2500 µT (z-axis), resolution ~0.3 µT, modes: low power, regular, enhanced regular, high accuracy |
| BMP280 Pressure Sensor | 300 ~ 1100 hPa, relative accuracy ±0.12 hPa (±1 m), absolute accuracy ±1 hPa (±8.33 m) |
| BMP280 Temperature Range | 0℃ ~ 65℃, resolution 0.01℃ |
| Operating Temperature | -40℃ ~ 80℃ |
| Dimension | 32 × 27 mm (1.26 × 1.06 in) |

<hr>

- #### **Touch Sensor** : ZX-Switch01 by INEX
This button gives us an easier way to start the robot. Since the controller board doesn't come with switches. So, we found this button that could be attached to the frame outside the board using bolt. 

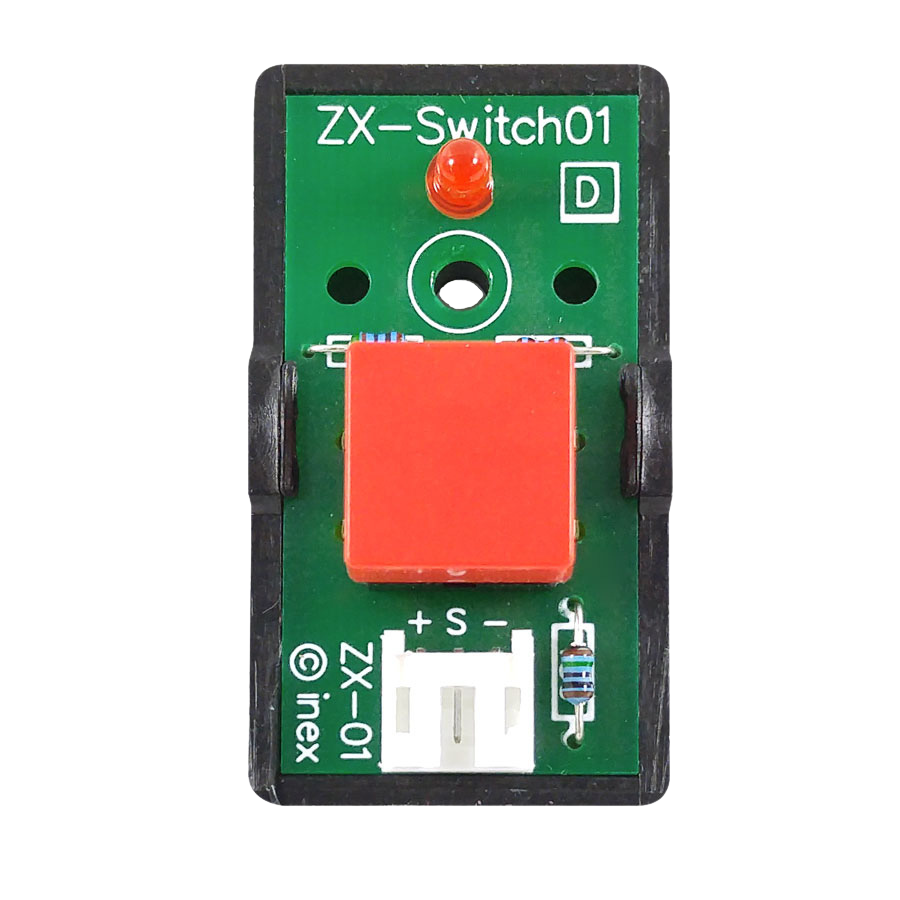
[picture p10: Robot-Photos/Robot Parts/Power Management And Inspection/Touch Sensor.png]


<hr>

- #### **On/Off Switch** : SPST ON/OFF Switch 2 Pin Rocker Switch DC 125/250V
This switch is for cutting the power from the battery to the robot. The regulation states that before starting the robot, the power must be cut off. That's when this switch came in. To use this switch, we solder red wire (Positive pole) to the switch on 1 side for input. Then another solder red wire for output on the opposite side. You can put the black wire (Negative pole) straight into the step-down. When the switch is turned on, the power from the battery will direct into the stepdown and then the robot. Additionally, we have designed a protective case for this switch to ensure safety and durability. [You can view the 3D model here](https://github.com/Book2009/YB-SUNFLOWER/blob/main/3DModels/Switch%20Box.stl).

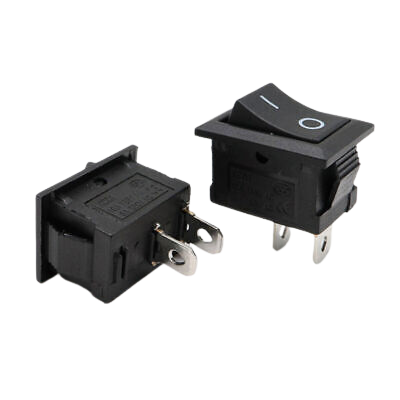
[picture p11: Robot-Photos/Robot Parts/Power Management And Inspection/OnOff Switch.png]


<hr>

- #### **Step-down** : LM2596
The LM2596 step-down converter is used to supply the Raspberry Pi with a dedicated 5 V power rail. Since the Pi is sensitive to voltage fluctuations and electrical noise, relying on the same power source as the motors could cause sudden resets or instability. By using this compact module exclusively for the Pi, we ensure a stable supply that remains unaffected by high current changes elsewhere in the system. The output is tuned to around 5.1 V to compensate for cable and connector losses, providing a consistent and reliable 5.0 V input to the Pi during operation.



##### Input

| Specification | Value |
|---|---|
| Input voltage | DC 4.5 ~ 40V |

##### Output

| Specification | Value |
|---|---|
| Output voltage | DC 1.25V ~ 37V (adjustable) |
| Output current | Up to 2A (without heatsink), 3A max with heatsink |
| Output power | ≤ 15W (typical), up to 20W with heatsink |

##### Performance

| Specification | Value |
|---|---|
| Conversion efficiency | Up to 92% |
| Switching frequency | ~150 kHz |
| Load regulation | ±0.5% |
| Voltage regulation | ±2.5% |

##### Measurements

| Specification | Value |
|---|---|
| Module dimension | ~43 × 21 × 14 mm |
| Typical voltage ripple  | ~30 mV |

<hr>

- #### **Step-down** : HW-360 V6.0
The HW316E V6.0.1 step-down converter is dedicated to supplying the motor shield and the drive motors, which draw significantly higher current than the Raspberry Pi. This module features a built-in digital display that shows the input voltage, which corresponds directly to the shared battery pack. Because both the LM2596 and HW316E draw from the same battery, a single display on the HW316E is sufficient to monitor the pack’s remaining voltage and determine when recharging is necessary. By isolating the motor power from the logic supply and providing real-time monitoring of the battery, this module ensures reliable performance for the drivetrain while simplifying overall system management.

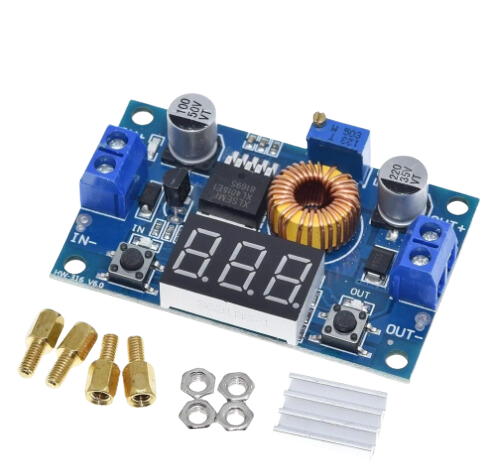
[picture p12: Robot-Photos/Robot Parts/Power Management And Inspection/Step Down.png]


##### Input

| Specification | Value |
|---|---|
| Input voltage | DC 4.0 ~ 38V |

##### Output

| Specification | Value |
|---|---|
| Output voltage | DC 1.25V ~ 36V continuously adjustable |
| Output current | Max 5A |
| Output power | Up to 75W |

##### Measurements

| Specification | Value |
|---|---|
| Voltmeter error | ± 0.05V |
| Measure range | 0 ~ 40V |

##### Performance

| Specification | Value |
|---|---|
| Conversion efficiency | Up to 96% |
| Load regulation | S (I) ≤ 0.8% |
| Voltage Regulation | S (u) ≤ 0.8% |

<hr>

- #### **Quick Wire Connector** : PCT-21 a3nd D1-2 Connector

PCT-21 Connector

<image src = "https://github.com/ThanyawutII/Test2/blob/main/80755_0.jpg" width = "400">

D1-2 Connector

<image src = "https://github.com/ThanyawutII/Test2/blob/main/80754_0.jpg" width = "400">

The robot’s power distribution system is designed around a single battery pack, which is split into two separate branches to supply both the Raspberry Pi and the motor shield. The positive pole of the battery is connected through the PCT-213 connector, where it is divided into multiple outputs, one directed to each step-down converter. The negative pole is handled by the D1-2 connector, providing a secure and stable ground reference that is also split between the converters. From there, the LM2596 module regulates clean 5 V power for the Raspberry Pi, while the HW316E V6.0.1 module delivers high-current power to the motor shield and motors. This arrangement ensures that both control logic and drivetrain receive isolated, stable power from the same battery source, while the connectors simplify wiring, improve safety, and make the system easier to maintain.

<hr>

- #### **Battery** : 11.1 voltage 3 cell Lipo-Battery.
<image src="https://github.com/ThanyawutII/Test/blob/main/Screenshot_2024-10-22_112329-removebg-preview.png" width = "400">
We upgraded from a 7.4V battery to an 11.1V battery due to reliability concerns and the limited capacity of the 7.4V option. The 11.1V battery enhances the robot's performance by providing higher voltage, which reduces current draw and minimizes power losses during operation. This upgrade ensures stable and continuous functionality without significant voltage drops, even under high current loads, a critical factor during intense practice sessions and competitions.

To ensure compatibility with our motor's maximum voltage rating of 9V, we incorporated a step-down voltage regulator. This module efficiently converts the 11.1V input to a stable 9V output, maintaining the motor's safety while maximizing the extended runtime afforded by the 11.1V battery. This solution not only improves reliability but also instills confidence in the system's durability and performance under demanding conditions.

##### Specification

| Specification | Value |
|---|---|
| 3 cells Voltage | 11.1V |
| Capacity | 1300mAh 20C |
| Charging Current | Up to 5 times the capacity (5C) |
| Connectors | Dean type, easily disconnectable |

<br><hr>

### Robot

- #### **This is the appearance of our robot in real life to show what our robot looks like with the components.**
<p align="center">
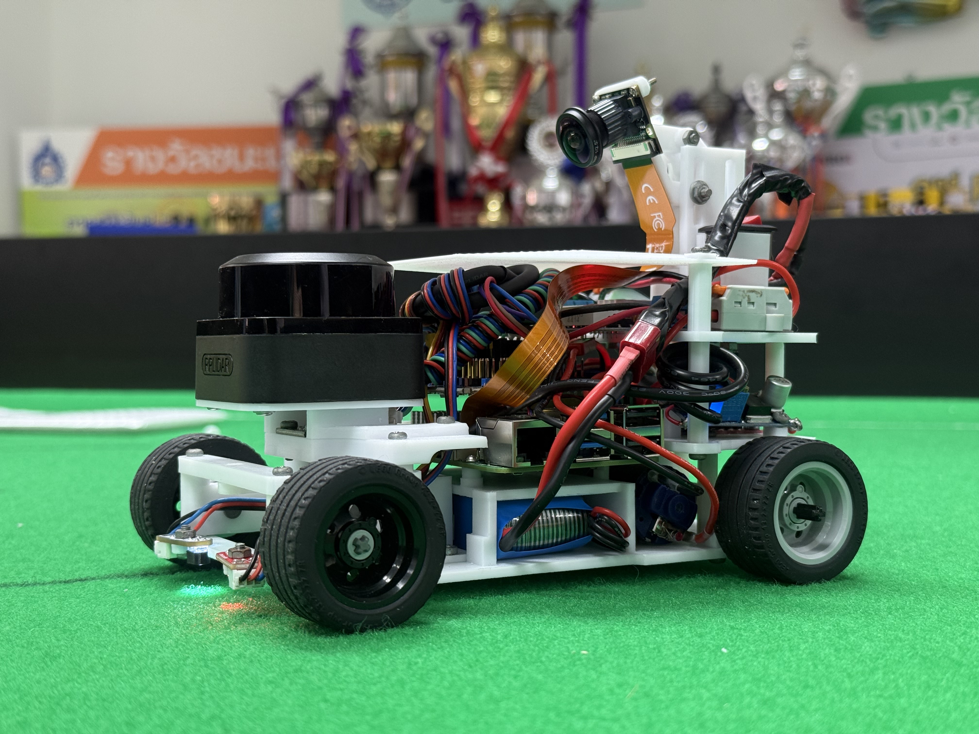
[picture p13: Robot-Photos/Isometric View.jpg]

</p>

- #### **It shows the inside of the robot, detailing where and how to place everything.**
<p align="center">
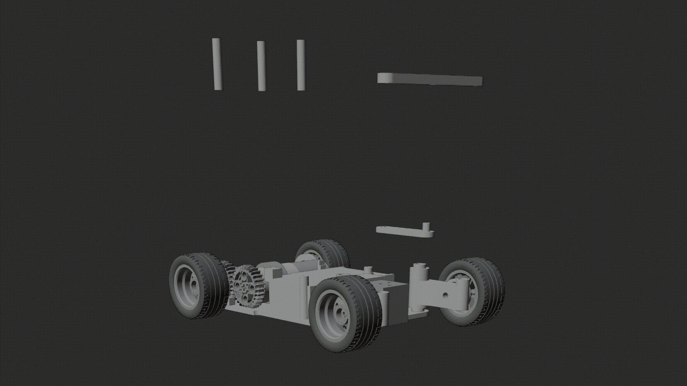
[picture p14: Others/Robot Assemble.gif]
    

<br><hr>

### Wiring Diagram and Power Distribution Diagram
- #### **It shows you the connection of various components to the microcontroller.**
<p align="center">
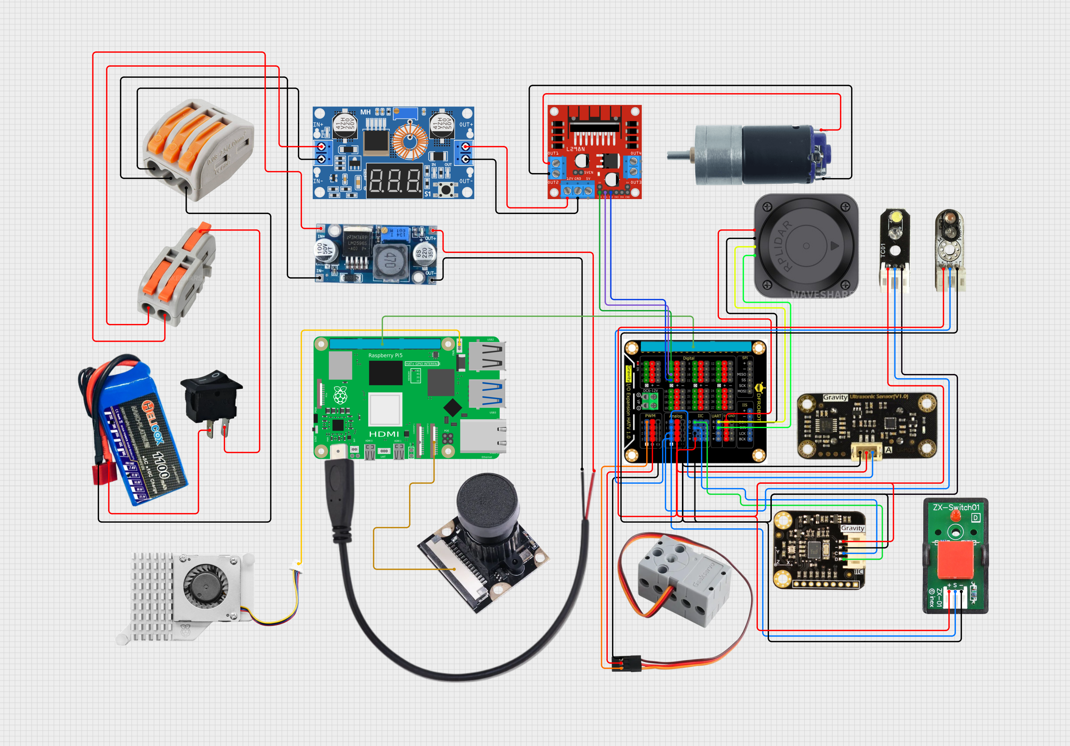
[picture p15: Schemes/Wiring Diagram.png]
    

- #### **It shows the ports of various components connected to the microcontroller, as well as the voltage levels supplied to the microcontroller and its connected components.**
<p align="center">
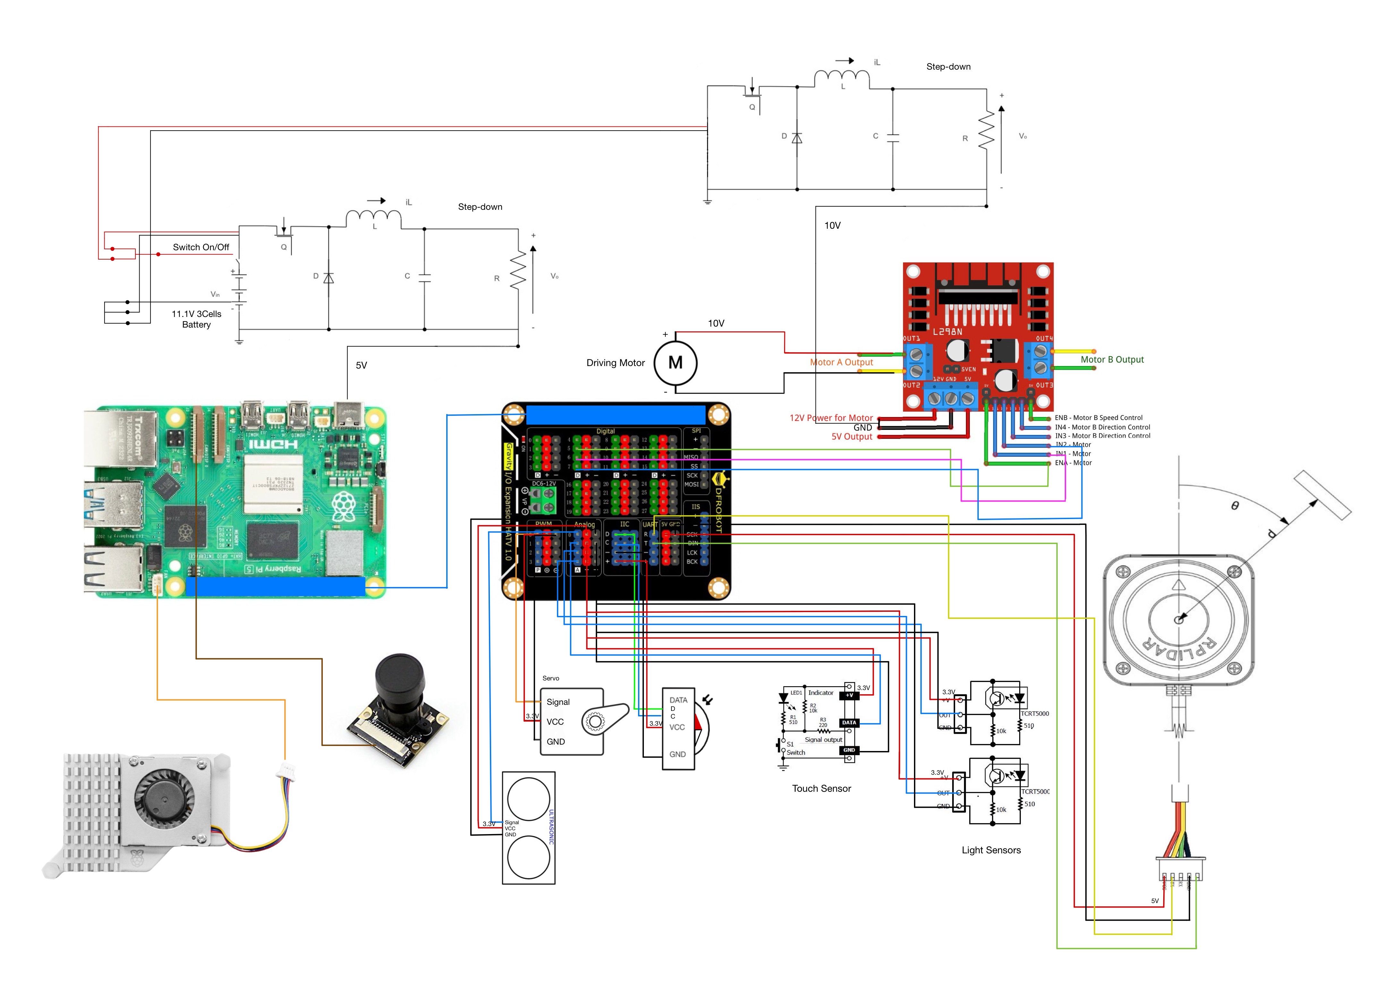
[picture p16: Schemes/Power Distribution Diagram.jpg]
    

<br><hr>

# **Part 3: Obstacle Management**

### **Open Challenge round (Youtube Link)**

This video shows our robot completing the first round(Open Challenge), you can [click here](https://youtu.be/-mydtj7d2Hc) to view the video we created.

<div align="center">
  <a href="https://youtu.be/-mydtj7d2Hc">
    
  </a>
</div>

<br><hr>

### **Flowchart**

<image src="https://github.com/Book2009/YB-SUNFLOWER/blob/main/FlowChart/Open_Challenge.jpg" height = "900">

<br><hr>

## Program Explanation - Open Round

### **Table of Contents**
1. [Overview](#overview)
2. [Library Imports and Setup](#imports)
3. [GPIO Initialization](#gpio)
4. [Configuration Constants](#constants)
5. [Helper Functions](#helpers)
6. [SimpleMotor Class](#motor)
7. [Vehicle Class - Initialization](#vehicle-init)
8. [Compass System](#compass)
9. [LiDAR System](#lidar)
10. [Light Sensor](#light-sensor)
11. [Turn Decision Strategy](#turn-decision)
12. [Motor Control and Steering](#motor-control)
13. [Navigation System](#navigation)
14. [90-Degree Turn Execution](#turning)
15. [Main Mission Loop](#mission)
16. [Complete Mission Flow](#flow)

---

## 1. Overview

This is a WRO (World Robot Olympiad) Future Engineers autonomous robot that:
- Navigates a track with walls on both sides
- Detects corner lines using a light sensor
- Makes turn decisions based on LiDAR side clearance measurements
- Completes 12 turns (3 laps × 4 corners)
- Stops when it returns to the starting position

**Key Strategy:**
- When it detects the first corner line, it checks which side has more than 2000mm of clearance
- It turns toward that clear side
- For all remaining 11 turns, it uses the same direction

---

## 2. Library Imports and Setup

```python
import sys
sys.path.append("/home/Book_Pi/DFRobot_RaspberryPi_Expansion_Board")
from DFRobot_RaspberryPi_Expansion_Board import DFRobot_Expansion_Board_IIC as Board
from DFRobot_RaspberryPi_Expansion_Board import DFRobot_Expansion_Board_Servo as Servo
```

**Purpose:** Imports the DFRobot expansion board libraries for:
- Reading analog sensors (light sensors)
- Controlling servo motors (steering)

```python
import serial
import time
from collections import deque
```

**Purpose:**
- `serial`: Communicate with LiDAR sensor via UART
- `time`: Timing control and delays
- `deque`: Efficient buffer for storing LiDAR data

```python
import RPi.GPIO as GPIO
```

**Purpose:** Control Raspberry Pi GPIO pins for motor control

```python
import board as board_pins
import busio
import adafruit_bno055
COMPASS_AVAILABLE = True
```

**Purpose:** 
- `board_pins`: Pin definitions for I2C communication
- `busio`: I2C communication interface
- `adafruit_bno055`: BNO055 compass sensor library
- Sets compass availability flag

---

## 3. GPIO Initialization

```python
print("Initializing GPIO...")
try:
    GPIO.cleanup()
except:
    pass

time.sleep(0.2)
GPIO.setmode(GPIO.BCM)
GPIO.setwarnings(False)
```

**What this does:**
1. `GPIO.cleanup()`: Clears any previous GPIO configurations (prevents conflicts)
2. `time.sleep(0.2)`: Waits 200ms for cleanup to complete
3. `GPIO.setmode(GPIO.BCM)`: Uses Broadcom pin numbering (GPIO numbers, not physical pin numbers)
4. `GPIO.setwarnings(False)`: Suppresses warning messages

**Why cleanup first?**
If the program crashed previously, GPIO pins might still be configured. Cleanup ensures a fresh start.

```python
# Motor pins
MOTOR_IN1 = 6
MOTOR_IN2 = 7
MOTOR_ENA = 5

# Setup motor pins
print("Setting up motor pins...")
try:
    GPIO.setup([MOTOR_IN1, MOTOR_IN2, MOTOR_ENA], GPIO.OUT, initial=GPIO.LOW)
    print("GPIO pins configured successfully")
except Exception as e:
    print(f"GPIO setup warning: {e}")
```

**Motor pin configuration:**
- `MOTOR_IN1` (GPIO 6): Motor direction control (forward/backward)
- `MOTOR_IN2` (GPIO 7): Motor direction control (forward/backward)
- `MOTOR_ENA` (GPIO 5): Motor enable pin with PWM speed control

**Pin setup:**
- `GPIO.OUT`: Configures pins as outputs
- `initial=GPIO.LOW`: Sets all pins to LOW (0V) initially to prevent motor from running

---

## 4. Configuration Constants

### Servo Configuration

```python
SERVO_CHANNEL = 0
SERVO_CENTER = 92
MAX_TURN_ANGLE = 45
```

**Explanation:**
- `SERVO_CHANNEL = 0`: Uses channel 0 on the expansion board
- `SERVO_CENTER = 92`: The servo angle value for driving straight (calibrated value)
- `MAX_TURN_ANGLE = 45`: Maximum steering angle (±45 degrees from center)

### LiDAR Configuration

```python
LIDAR_PORT = '/dev/ttyAMA0'
LIDAR_BAUD = 460800
```

**Explanation:**
- `LIDAR_PORT`: Serial port where LiDAR is connected (Raspberry Pi's primary UART)
- `LIDAR_BAUD`: Communication speed (460,800 bits per second)

### Light Sensor Configuration

```python
LIGHT_SENSOR_A3 = 3
LINE_THRESHOLD = 2600
```

**Explanation:**
- `LIGHT_SENSOR_A3 = 3`: Light sensor connected to analog input A3
- `LINE_THRESHOLD = 2600`: Values below this indicate a dark line
  - Light surface: ~3000-4000
  - Dark line: <2600

### LiDAR Angle Zones

```python
FRONT_MIN = 355
FRONT_MAX = 5
LEFT_MIN = 265
LEFT_MAX = 275
RIGHT_MIN = 85
RIGHT_MAX = 95
```

**How LiDAR angles work:**
LiDAR measures 360° around the robot:
```
        0° (Front)
           |
   270° ---|--- 90°
           |
       180° (Back)
```

**Zone definitions:**
- **Front zone**: 355°-360° and 0°-5° (wraps around 0°)
- **Left zone**: 265°-275° (10° window pointing left)
- **Right zone**: 85°-95° (10° window pointing right)

**Why narrow zones (10° instead of 40°)?**
- More precise wall distance measurements
- Reduces interference from diagonal walls
- Better for tight corridor navigation

### Turn Decision Parameter

```python
LIDAR_SIDE_CLEARANCE_THRESHOLD = 2000
```

**Critical parameter:** Robot turns toward whichever side has more than 2000mm (2 meters) of clearance.

**Why 2000mm?**
- Typical WRO obstacle sections: pillars are placed ~1500mm from the wall
- Open corner areas: usually >2000mm clearance
- This threshold reliably distinguishes between "obstacle side" vs "open side"

### Compass Configuration

```python
HEADING_TOLERANCE = 10
HEADING_KP = 0.5
```

**Explanation:**
- `HEADING_TOLERANCE = 10`: Turn is complete when within ±10° of target heading
- `HEADING_KP = 0.5`: Proportional gain for compass-based steering correction

### Speed Configuration

```python
BASE_SPEED = 55
SLOW_SPEED = 50
TURN_SPEED = 50
```

**Speed values (0-100 scale):**
- `BASE_SPEED = 55`: Normal driving speed
- `SLOW_SPEED = 50`: Used when close to walls or turning
- `TURN_SPEED = 50`: Speed during 90-degree turns

### Wall Following Parameters

```python
TARGET_WALL_WIDE = 450
TARGET_WALL_NARROW = 250
MIN_SAFE_DISTANCE = 180
KP_WALL = 0.04
KD_WALL = 0.025
```

**Wall following behavior:**
- `TARGET_WALL_WIDE = 450`: Tries to maintain 450mm from wall in wide corridors
- `TARGET_WALL_NARROW = 250`: Tries to maintain 250mm from wall in narrow corridors
- `MIN_SAFE_DISTANCE = 180`: Emergency distance - slows down if closer than 180mm
- `KP_WALL = 0.04`: Proportional gain for wall-following steering
- `KD_WALL = 0.025`: Derivative gain for wall-following steering (damping)

**PD Control explanation:**
- **P (Proportional)**: Steers harder when farther from target distance
- **D (Derivative)**: Reduces steering when approaching target (prevents oscillation)

### Turn Execution Parameters

```python
FRONT_TURN_THRESHOLD = 700
PRE_TURN_STEER_ANGLE = 30
REVERSE_SPEED = 50
```

**Explanation:**
- `FRONT_TURN_THRESHOLD = 700`: Considers front obstacle when within 700mm
- `PRE_TURN_STEER_ANGLE = 30`: Steering angle applied during turns (±30°)
- `REVERSE_SPEED = 50`: Speed for backing up (not used in current code, but available)

### Board Initialization

```python
board = Board(1, 0x10)
```

**Purpose:** Creates global expansion board object
- `1`: I2C bus number
- `0x10`: I2C address of the expansion board

---

## 5. Helper Functions

### Normalize Angle

```python
def normalize_angle(angle):
    while angle < 0:
        angle += 360
    while angle >= 360:
        angle -= 360
    return angle
```

**Purpose:** Keeps angles within 0-360° range

**Examples:**
- Input: 450° → Output: 90° (450 - 360 = 90)
- Input: -45° → Output: 315° (-45 + 360 = 315)
- Input: 180° → Output: 180° (already in range)

**Why needed?**
Compass readings and turn calculations can produce angles outside 0-360° range. This function wraps them back.

### Angle Difference

```python
def angle_difference(target, current):
    diff = target - current
    if diff > 180:
        diff -= 360
    elif diff < -180:
        diff += 360
    return diff
```

**Purpose:** Calculates the shortest angular distance between two angles

**Examples:**
- Target: 10°, Current: 350° → Difference: +20° (not -340°)
- Target: 350°, Current: 10° → Difference: -20° (not +340°)
- Target: 180°, Current: 90° → Difference: +90°

**Why needed?**
Without this, the robot might turn 340° counterclockwise instead of 20° clockwise.

**How it works:**
```
If difference > 180°: subtract 360° (go the other way)
If difference < -180°: add 360° (go the other way)
```

### Correct LiDAR Angle

```python
def correct_lidar_angle(lidar_angle, heading_offset):
    corrected = lidar_angle - heading_offset
    return normalize_angle(corrected)
```

**Purpose:** Adjusts LiDAR readings based on robot's current heading

**Why needed?**
LiDAR measures angles relative to its own orientation. If the robot is facing 45° instead of 0°, the LiDAR readings need to be corrected.

**Example:**
```
Robot is facing 45° (heading_offset = 45°)
LiDAR detects wall at 90° (its own reference)
Corrected angle = 90° - 45° = 45° (actual wall direction relative to starting orientation)
```

**Process:**
1. Subtracts heading offset from LiDAR angle
2. Normalizes result to 0-360° range

---

## 6. SimpleMotor Class

```python
class SimpleMotor:
    def __init__(self, in1, in2, ena):
        self.in1, self.in2, self.ena = in1, in2, ena
        
        print("Configuring motor pins...")
        
        # Motor control pins
        GPIO.setup(self.in1, GPIO.OUT)
        GPIO.setup(self.in2, GPIO.OUT)
        GPIO.setup(self.ena, GPIO.OUT)
        
        # PWM
        self.pwm = GPIO.PWM(self.ena, 1000)
        self.pwm.start(0)
        print("Motor configured successfully")
```

**Initialization:**
1. Stores pin numbers (IN1, IN2, ENA)
2. Configures GPIO pins as outputs
3. Creates PWM object on ENA pin at 1000 Hz frequency
4. Starts PWM at 0% duty cycle (motor off)

**Motor control logic:**
- **IN1 HIGH, IN2 LOW**: Motor spins forward
- **IN1 LOW, IN2 HIGH**: Motor spins backward
- **ENA PWM duty cycle**: Controls speed (0-100%)

### Set Speed Method

```python
def set_speed(self, speed):
    speed = max(-100, min(100, speed))
    try:
        if speed > 0:
            GPIO.output(self.in1, GPIO.HIGH)
            GPIO.output(self.in2, GPIO.LOW)
            self.pwm.ChangeDutyCycle(abs(speed))
        elif speed < 0:
            GPIO.output(self.in1, GPIO.LOW)
            GPIO.output(self.in2, GPIO.HIGH)
            self.pwm.ChangeDutyCycle(abs(speed))
        else:
            self.stop()
    except Exception as e:
        print(f"Motor speed error: {e}")
```

**How it works:**

1. **Speed clamping:** `speed = max(-100, min(100, speed))`
   - Ensures speed is between -100 and +100
   - Example: set_speed(150) → actually uses 100

2. **Forward (speed > 0):**
   ```
   IN1 = HIGH, IN2 = LOW
   PWM = speed value (0-100%)
   ```

3. **Backward (speed < 0):**
   ```
   IN1 = LOW, IN2 = HIGH
   PWM = absolute value of speed
   ```

4. **Stop (speed = 0):**
   - Calls the stop() method

**Example:**
```python
motor.set_speed(75)   # Forward at 75% power
motor.set_speed(-50)  # Backward at 50% power
motor.set_speed(0)    # Stop
```

### Stop Method

```python
def stop(self):
    try:
        GPIO.output(self.in1, GPIO.LOW)
        GPIO.output(self.in2, GPIO.LOW)
        self.pwm.ChangeDutyCycle(0)
    except:
        pass
```

**Purpose:** Completely stops the motor
- Sets both IN1 and IN2 to LOW
- Sets PWM to 0%
- Uses `try/except` to handle potential errors gracefully

### Cleanup Method

```python
def cleanup(self):
    self.stop()
    try:
        self.pwm.stop()
    except:
        pass
```

**Purpose:** Proper shutdown procedure
1. Stops the motor
2. Stops the PWM signal
3. Should be called before program exits

---

## 7. Vehicle Class - Initialization

```python
class Vehicle:
    def __init__(self):
        print("\n" + "="*70)
        print(" WRO FUTURE ENGINEERS 2025 - LIDAR TURN DECISION")
        print("="*70)
        
        self._init_board()
        self._init_motor()
        self._init_servo()
        self._init_compass()
        self._init_lidar()
```

**Initialization sequence:**
The `__init__` method calls five initialization functions in order. Each must succeed before moving to the next.

### State Variables

```python
        # Compass navigation
        self.initial_heading = None
        self.target_heading = None
        self.heading_offset = 0
```

**Compass variables:**
- `initial_heading`: The compass direction when the robot starts (e.g., 0°)
- `target_heading`: Where the robot should be pointing now (updates after each turn)
- `heading_offset`: Error between where robot should point vs. where it actually points

**Example:**
```
initial_heading = 0° (start facing north)
After 1st turn: target_heading = 90° (should face east)
If compass reads 85°: heading_offset = +5° (pointing 5° too far left)
```

```python
        # Mission state
        self.turn_count = 0
        self.turn_direction = None  # Will be set by first LiDAR decision
```

**Mission tracking:**
- `turn_count`: How many turns completed (0-12)
- `turn_direction`: Memorized direction ('left' or 'right', starts as None)

**The key strategy:**
- First corner: robot decides 'left' or 'right' based on LiDAR
- Remaining 11 corners: robot uses the same memorized direction

```python
        # Navigation state
        self.last_left_error = 0
        self.last_right_error = 0
        self.current_speed = BASE_SPEED
        self.navigation_mode = "wall_follow"
```

**Navigation variables:**
- `last_left_error`: Previous error from left wall (for derivative calculation)
- `last_right_error`: Previous error from right wall (for derivative calculation)
- `current_speed`: Current motor speed value
- `navigation_mode`: Current behavior ("wall_follow" or "turning")

```python
        # Turn sequence state
        self.waiting_for_clearance = False
        self.line_detected_time = 0
```

**Turn state machine:**
- `waiting_for_clearance`: True when robot detected a line and is waiting to turn
- `line_detected_time`: Timestamp when line was detected (for timeout protection)

**Two-phase turn sequence:**
```
Phase 1: Detect line → set waiting_for_clearance = True
Phase 2: Check side clearance → turn → set waiting_for_clearance = False
```

```python
        # Corridor width
        self.corridor_width_history = deque(maxlen=20)
```

**Corridor tracking:**
- Stores the last 20 measurements of total corridor width (left + right distances)
- Used to determine if in "wide" or "narrow" corridor
- Automatically removes old data when full (FIFO - First In First Out)

```python
        # Steering
        self.steering_history = deque(maxlen=3)
```

**Smooth steering:**
- Stores the last 3 steering commands
- Averages them for smoother steering transitions
- Prevents jerky movements

```python
        # LiDAR
        self.lidar_buffer = bytearray()
        self.front_data = deque(maxlen=10)
        self.left_data = deque(maxlen=10)
        self.right_data = deque(maxlen=10)
```

**LiDAR data storage:**
- `lidar_buffer`: Raw bytes received from LiDAR (unparsed)
- `front_data`: Last 10 front distance readings
- `left_data`: Last 10 left distance readings  
- `right_data`: Last 10 right distance readings

**Why deque with maxlen=10?**
- Automatically removes oldest reading when adding 11th reading
- Provides averaging over recent data (noise reduction)
- Fixed memory usage (doesn't grow indefinitely)

### Board Initialization

```python
def _init_board(self):
    print("[1/5] Expansion Board...")
    self.board = Board(1, 0x10)
    while self.board.begin() != self.board.STA_OK:
        time.sleep(1)
    self.board.set_adc_enable()
    print("  OK")
```

**Process:**
1. Creates Board object (I2C bus 1, address 0x10)
2. Calls `board.begin()` repeatedly until it returns `STA_OK` (board ready)
3. Enables ADC (Analog-to-Digital Converter) for light sensors
4. Prints confirmation

**Why the while loop?**
The expansion board needs time to initialize. If it's not ready, the program waits 1 second and tries again.

### Motor Initialization

```python
def _init_motor(self):
    print("[2/5] Simple Motor...")
    self.motor = SimpleMotor(MOTOR_IN1, MOTOR_IN2, MOTOR_ENA)
    print("  OK")
```

**Process:**
- Creates SimpleMotor object with pin numbers
- SimpleMotor.__init__() handles the actual GPIO setup

### Servo Initialization

```python
def _init_servo(self):
    print("[3/5] Servo...")
    self.servo_ctrl = Servo(self.board)
    self.servo_ctrl.begin()
    self.servo_ctrl.move(SERVO_CHANNEL, SERVO_CENTER)
    print("  OK")
```

**Process:**
1. Creates Servo controller object (uses the expansion board)
2. Calls `begin()` to initialize servo system
3. Moves servo to center position (92°) for straight driving
4. Prints confirmation

### Compass Initialization

```python
def _init_compass(self):
    print("[4/5] BNO055 Compass...")
    try:
        i2c = busio.I2C(board_pins.SCL, board_pins.SDA)
        self.compass = adafruit_bno055.BNO055_I2C(i2c)
        time.sleep(1)
        print("  OK")
    except:
        print("  FAILED (continuing without compass)")
        self.compass = None
```

**Process:**
1. Creates I2C bus object using SCL and SDA pins
2. Creates BNO055 compass object on that I2C bus
3. Waits 1 second for compass to stabilize
4. If any error occurs, sets `self.compass = None` and continues

**Why try/except?**
Compass failure shouldn't stop the entire program. The robot can still navigate using dead reckoning.

### LiDAR Initialization

```python
def _init_lidar(self):
    print("[5/5] LiDAR...")
    self.lidar = serial.Serial(port=LIDAR_PORT, baudrate=LIDAR_BAUD, timeout=1)
    
    print("  Sending scan command...")
    self.lidar.write(bytes([0xA5, 0x20]))
    time.sleep(0.5)
    response = self.lidar.read(7)
    print(f"  Scan response: {response.hex()}")
    print("  OK")
```

**Process:**
1. Opens serial connection to LiDAR at 460800 baud
2. Sends scan start command: `0xA5 0x20`
3. Waits 500ms for LiDAR to respond
4. Reads 7-byte response and displays it in hexadecimal
5. Prints confirmation

**LiDAR command breakdown:**
- `0xA5`: Command header byte
- `0x20`: "Start scan" command code

**Expected response format:**
```
Byte 0-1: Response header (0xA5 0x5A)
Byte 2: Response length
Byte 3: Command type
Byte 4-6: Additional data
```

---

## 8. Compass System

### Get Current Heading

```python
def heading(self):
    if self.compass:
        try:
            euler = self.compass.euler
            if euler and euler[0] is not None:
                return round(euler[0], 1)
        except:
            pass
    return None
```

**Purpose:** Returns robot's current compass heading

**Process:**
1. Checks if compass exists
2. Reads Euler angles from compass
3. Returns first Euler angle (heading) rounded to 0.1°
4. Returns `None` if compass unavailable or reading fails

**Euler angles explained:**
- `euler[0]`: Heading (0-360°, where 0° = north)
- `euler[1]`: Pitch (tilt forward/backward)
- `euler[2]`: Roll (tilt left/right)

**Example output:**
```python
heading() → 45.2    # Robot facing northeast
heading() → 180.0   # Robot facing south
heading() → None    # Compass error
```

### Set Initial Heading

```python
def set_initial_heading(self):
    heading = self.heading()
    if heading is not None:
        self.initial_heading = heading
        self.target_heading = heading
        print(f"Initial heading set: {self.initial_heading}°")
    else:
        print("WARNING: Could not set initial heading!")
```

**Purpose:** Records the robot's starting direction

**When called:** Once at mission start, after compass stabilizes

**What it does:**
1. Reads current heading
2. Sets both `initial_heading` and `target_heading` to this value
3. Prints confirmation or warning

**Example:**
```
Robot starts facing: 0°
initial_heading = 0°
target_heading = 0°

After 1st right turn (90°):
initial_heading = 0° (never changes)
target_heading = 90° (updated after turn)
```

### Update Heading Offset

```python
def update_heading_offset(self):
    current = self.heading()
    if current is not None and self.target_heading is not None:
        self.heading_offset = angle_difference(self.target_heading, current)
    else:
        self.heading_offset = 0
```

**Purpose:** Calculates how far off-course the robot is

**Process:**
1. Reads current heading from compass
2. Calculates difference between target and current heading
3. Stores result in `heading_offset`

**Example:**
```
target_heading = 90° (should be facing east)
current heading = 85° (actually facing slightly north of east)
heading_offset = 90° - 85° = +5° (need to turn right by 5°)
```

**Sign convention:**
- **Positive offset**: Robot is left of target, should turn right
- **Negative offset**: Robot is right of target, should turn left

### Calculate Heading Correction

```python
def calculate_heading_correction(self):
    if self.heading_offset == 0:
        return 0
    correction = -self.heading_offset * HEADING_KP
    return max(-30, min(30, correction))
```

**Purpose:** Converts heading error into steering adjustment

**Formula:** `correction = -heading_offset × HEADING_KP`

**Why negative?**
- If heading_offset = +5° (too far left), we want negative steering (turn right)
- If heading_offset = -5° (too far right), we want positive steering (turn left)

**Example calculations:**
```
HEADING_KP = 0.5

heading_offset = +10° → correction = -10 × 0.5 = -5° (steer right)
heading_offset = -8°  → correction = -(-8) × 0.5 = +4° (steer left)
heading_offset = +100° → correction = -50°, clamped to -30° (max right)
```

**Clamping:** `max(-30, min(30, correction))`
- Limits correction to ±30° maximum
- Prevents excessive steering commands

---

## 9. LiDAR System

### Update LiDAR

```python
def update_lidar(self):
    try:
        if self.lidar.in_waiting > 0:
            self.lidar_buffer.extend(self.lidar.read(self.lidar.in_waiting))
        
        self.update_heading_offset()
        
        while len(self.lidar_buffer) >= 5:
            point_data = self.lidar_buffer[:5]
            self.lidar_buffer = self.lidar_buffer[5:]
            
            point = self._parse_scan_point(point_data)
            if point and point['distance'] > 0:
                raw_angle = point['angle']
                corrected_angle = correct_lidar_angle(raw_angle, self.heading_offset)
                dist = point['distance']
                
                if self._is_front_angle(corrected_angle):
                    self.front_data.append(dist)
                elif self._is_left(corrected_angle):
                    self.left_data.append(dist)
                elif self._is_right(corrected_angle):
                    self.right_data.append(dist)
    except Exception as e:
        print(f"LiDAR update error: {e}")
```

**Purpose:** Main LiDAR processing function, called continuously in the main loop

**Step-by-step process:**

**Step 1: Read new data**
```python
if self.lidar.in_waiting > 0:
    self.lidar_buffer.extend(self.lidar.read(self.lidar.in_waiting))
```
- Checks if serial port has data waiting
- Reads all available bytes and adds to buffer
- `in_waiting`: Number of bytes in serial receive buffer

**Step 2: Update compass**
```python
self.update_heading_offset()
```
- Updates the robot's heading error
- Needed for angle correction

**Step 3: Parse data points**
```python
while len(self.lidar_buffer) >= 5:
    point_data = self.lidar_buffer[:5]
    self.lidar_buffer = self.lidar_buffer[5:]
```
- Each LiDAR point is 5 bytes
- Extracts first 5 bytes for processing
- Removes those 5 bytes from buffer

**Step 4: Process each point**
```python
point = self._parse_scan_point(point_data)
if point and point['distance'] > 0:
```
- Parses the 5-byte packet into angle and distance
- Checks if valid (distance > 0 means actual detection)

**Step 5: Correct angle and store**
```python
raw_angle = point['angle']
corrected_angle = correct_lidar_angle(raw_angle, self.heading_offset)
dist = point['distance']
```
- Gets raw angle from LiDAR
- Corrects it based on robot's current heading
- Extracts distance value

**Step 6: Sort into zones**
```python
if self._is_front_angle(corrected_angle):
    self.front_data.append(dist)
elif self._is_left(corrected_angle):
    self.left_data.append(dist)
elif self._is_right(corrected_angle):
    self.right_data.append(dist)
```
- Determines which zone the angle belongs to
- Adds distance to appropriate deque buffer

### Parse Scan Point

```python
def _parse_scan_point(self, data):
    if len(data) < 5:
        return None
    
    quality = (data[0] >> 2) & 0x3F
    angle_q6 = (data[1] >> 1) | (data[2] << 7)
    angle = (angle_q6 / 64.0) % 360.0
    distance_q2 = data[3] | (data[4] << 8)
    distance = distance_q2 / 4.0
    
    return {
        'angle': angle,
        'distance': distance,
        'quality': quality
    }
```

**Purpose:** Converts 5-byte LiDAR packet into useful data

**LiDAR packet format (5 bytes):**
```
Byte 0: [Quality(6 bits)][Start flag(1 bit)][Not used(1 bit)]
Byte 1-2: Angle data (15 bits)
Byte 3-4: Distance data (16 bits)
```

**Parsing breakdown:**

**1. Quality extraction:**
```python
quality = (data[0] >> 2) & 0x3F
```
- Right-shifts
byte 0 by 2 bits
- Masks with 0x3F (0011 1111) to get 6 bits
- Quality range: 0-63 (higher = better)

**2. Angle extraction:**
```python
angle_q6 = (data[1] >> 1) | (data[2] << 7)
angle = (angle_q6 / 64.0) % 360.0
```
- Combines bytes 1 and 2 into 15-bit number
- Divides by 64 (Q6 fixed-point format)
- Applies modulo 360 to get 0-360° range

**Example:**
```
data[1] = 0b10101010, data[2] = 0b00000001
Step 1: data[1] >> 1 = 0b01010101 (85)
Step 2: data[2] << 7 = 0b10000000 (128)
Step 3: angle_q6 = 85 | 128 = 213
Step 4: angle = 213 / 64.0 = 3.328°
```

**3. Distance extraction:**
```python
distance_q2 = data[3] | (data[4] << 8)
distance = distance_q2 / 4.0
```
- Combines bytes 3 and 4 into 16-bit number
- Divides by 4 (Q2 fixed-point format)
- Result in millimeters

**Example:**
```
data[3] = 0xE8 (232), data[4] = 0x03 (3)
Step 1: data[4] << 8 = 0x0300 (768)
Step 2: distance_q2 = 232 | 768 = 1000
Step 3: distance = 1000 / 4.0 = 250.0 mm
```

**Return format:**
```python
{
    'angle': 45.5,      # degrees (0-360)
    'distance': 1250.0, # millimeters
    'quality': 47       # signal quality (0-63)
}
```

### Angle Detection Methods

```python
def _is_front_angle(self, angle):
    return angle >= FRONT_MIN or angle <= FRONT_MAX
```

**Front detection:** 355° - 360° OR 0° - 5°

**Why "or" instead of "and"?**
The front zone wraps around 0°:
```
        0°/360°
    355° | 5°
        robot
```

**Examples:**
```python
_is_front_angle(358) → True  (358 >= 355)
_is_front_angle(2)   → True  (2 <= 5)
_is_front_angle(180) → False (not in range)
```

```python
def _is_left(self, angle):
    return abs(angle - LEFT_MIN) <= 5
```

**Left detection:** Within 5° of 265°

**Formula:** `|angle - 265°| ≤ 5°`

**Examples:**
```python
_is_left(265) → True  (|265-265| = 0 ≤ 5)
_is_left(270) → True  (|270-265| = 5 ≤ 5)
_is_left(262) → True  (|262-265| = 3 ≤ 5)
_is_left(280) → False (|280-265| = 15 > 5)
```

**Effective range:** 260° - 270°

```python
def _is_right(self, angle):
    return abs(angle - RIGHT_MIN) <= 5
```

**Right detection:** Within 5° of 85°

**Effective range:** 80° - 90°

**Visual representation:**
```
           0° (Front: 355-5°)
            |
    265° ---|--- 85°
    (Left:  |  (Right:
   260-270°)|  80-90°)
            |
          180°
```

### Distance Methods

```python
def distance_front(self):
    if self.front_data:
        return round(sum(self.front_data) / len(self.front_data))
    return None
```

**Purpose:** Returns average front distance from recent readings

**How it works:**
1. Checks if `front_data` deque has any readings
2. Sums all values
3. Divides by count to get average
4. Rounds to nearest integer (millimeter)
5. Returns `None` if no data available

**Example:**
```python
front_data = [1200, 1180, 1220, 1190, 1210]

sum = 6000
len = 5
average = 6000 / 5 = 1200 mm
```

**Why averaging?**
- Reduces noise from individual readings
- Provides more stable distance values
- With `maxlen=10`, averages over ~0.2 seconds of data

```python
def distance_left(self):
    if self.left_data:
        return round(sum(self.left_data) / len(self.left_data))
    return None

def distance_right(self):
    if self.right_data:
        return round(sum(self.right_data) / len(self.right_data))
    return None
```

**Same logic for left and right distances**

**Return values:**
- Integer (mm) if data available
- `None` if no recent readings

---

## 10. Light Sensor

### Read Light Sensor

```python
def read_light_sensor_a3(self):
    """Read only A3 light sensor"""
    try:
        value = self.board.get_adc_value(LIGHT_SENSOR_A3)
        return value
    except:
        return None
```

**Purpose:** Reads the analog light sensor value

**How it works:**
1. Calls `get_adc_value()` with sensor channel (3)
2. Returns raw ADC value (typically 0-4095)
3. Returns `None` if read fails

**Light sensor behavior:**
- **Bright surface (white mat):** High values (~3000-4000)
- **Dark surface (orange/blue line):** Low values (~1000-2500)
- **Very dark:** Very low values (<1000)

### Detect Line

```python
def detect_line(self):
    """
    Detect line using ONLY A3 sensor
    Returns: True if line detected, False otherwise
    """
    a3_value = self.read_light_sensor_a3()
    
    if a3_value is None:
        return False
    
    # Line detected when sensor reads below threshold (dark line)
    if a3_value < LINE_THRESHOLD:
        print(f">>> LINE DETECTED! A3 sensor: {a3_value}")
        return True
    
    return False
```

**Purpose:** Determines if robot is over a corner line

**Detection logic:**
```
if sensor_value < 2600:
    → Line detected (dark surface)
else:
    → No line (light surface)
```

**Example scenarios:**
```python
# On white mat
a3_value = 3200
3200 < 2600? No → False (no line)

# On orange corner line
a3_value = 2100
2100 < 2600? Yes → True (line detected!)

# Sensor error
a3_value = None
→ False (safe default)
```

**Why print when detected?**
- Provides visual feedback during operation
- Helps with debugging and monitoring
- Shows actual sensor value for calibration

**Threshold calibration:**
The `LINE_THRESHOLD = 2600` value should be adjusted based on:
- Ambient lighting conditions
- Mat color and condition
- Line color (orange or blue)
- Sensor positioning and height

---

## 11. Turn Decision Strategy

```python
def decide_turn_direction_lidar(self):
    """
    NEW: Decide turn direction based on which side has > 1500mm clearance
    Returns: 'left' if left side is clear, 'right' if right side is clear
    """
    left_dist = self.distance_left()
    right_dist = self.distance_right()
    
    print(f"\n  LiDAR Turn Decision:")
    print(f"    Left side: {left_dist}mm")
    print(f"    Right side: {right_dist}mm")
    print(f"    Threshold: {LIDAR_SIDE_CLEARANCE_THRESHOLD}mm")
```

**Purpose:** This is the core strategy - determines which direction to turn based on LiDAR measurements

**Strategy overview:**
1. Measure distances on both sides
2. Check which side has > 2000mm clearance
3. Turn toward the clear side
4. Remember this direction for all future turns

### Handle Missing Data

```python
    if left_dist is None:
        left_dist = 0
    if right_dist is None:
        right_dist = 0
```

**Safety handling:** If LiDAR can't read a side (no data), treats it as 0mm

**Why this matters:**
- Prevents program crashes from `None` values
- Ensures that side won't be chosen (0mm is never > 2000mm)
- Allows decision logic to continue even with partial data

### Decision Logic

```python
    # Check which side has > 1500mm clearance
    left_clear = left_dist > LIDAR_SIDE_CLEARANCE_THRESHOLD
    right_clear = right_dist > LIDAR_SIDE_CLEARANCE_THRESHOLD
```

**Clearance check:**
- `left_clear = True` if left distance > 2000mm
- `right_clear = True` if right distance > 2000mm

**What 2000mm clearance means:**
- WRO obstacle sections: Pillars typically ~1200-1500mm from wall
- Open corners: Usually >2000mm clearance
- This threshold reliably distinguishes "obstacle side" vs "open side"

### Case 1: Only Left Clear

```python
    if left_clear and not right_clear:
        print(f"  → LEFT side is CLEAR ({left_dist}mm > {LIDAR_SIDE_CLEARANCE_THRESHOLD}mm)")
        return 'left'
```

**Scenario:**
```
Left: 2300mm (clear!) 
Right: 1400mm (blocked by obstacle)
Decision: Turn LEFT
```

**Why?**
The right side has an obstacle (pillar), so turning right would hit it. Left side is open, so turn that way.

### Case 2: Only Right Clear

```python
    elif right_clear and not left_clear:
        print(f"  → RIGHT side is CLEAR ({right_dist}mm > {LIDAR_SIDE_CLEARANCE_THRESHOLD}mm)")
        return 'right'
```

**Scenario:**
```
Left: 1300mm (blocked by obstacle)
Right: 2500mm (clear!)
Decision: Turn RIGHT
```

### Case 3: Both Sides Clear

```python
    elif left_clear and right_clear:
        # Both clear, pick the clearer one
        if left_dist > right_dist:
            print(f"  → BOTH clear, LEFT is clearer ({left_dist}mm > {right_dist}mm)")
            return 'left'
        else:
            print(f"  → BOTH clear, RIGHT is clearer ({right_dist}mm >= {left_dist}mm)")
            return 'right'
```

**Scenario:**
```
Left: 2400mm (clear)
Right: 2100mm (clear)
Both > 2000mm threshold
Decision: Turn LEFT (2400 > 2100)
```

**Why choose the clearer side?**
- More room to maneuver
- Less risk of hitting walls during turn
- Better for obstacle avoidance courses

### Case 4: Neither Side Clear

```python
    else:
        # Neither clear, pick the larger one
        if left_dist > right_dist:
            print(f"  → NEITHER > {LIDAR_SIDE_CLEARANCE_THRESHOLD}mm, choosing LEFT ({left_dist}mm > {right_dist}mm)")
            return 'left'
        else:
            print(f"  → NEITHER > {LIDAR_SIDE_CLEARANCE_THRESHOLD}mm, choosing RIGHT ({right_dist}mm >= {left_dist}mm)")
            return 'right'
```

**Scenario:**
```
Left: 1800mm (not clear, but larger)
Right: 1500mm (not clear, smaller)
Neither > 2000mm threshold
Decision: Turn LEFT (1800 > 1500 - best available)
```

**Why this case exists:**
- Narrow tracks where neither side reaches 2000mm
- Early detection before reaching full clearance
- Still makes a reasonable decision based on available space

**Example decision flow:**
```
Corner approach:
Time 0s: L:1200mm R:1100mm → neither clear, keep driving
Time 1s: L:1500mm R:1300mm → neither clear, keep driving
Time 2s: L:1900mm R:1600mm → neither clear, keep driving
Time 3s: L:2100mm R:1700mm → LEFT CLEAR! Decide "left"
Turn left, remember "left" for all future turns
```

---

## 12. Motor Control and Steering

### Forward Movement

```python
def forward(self, speed=BASE_SPEED):
    self.motor.set_speed(speed)
    self.current_speed = speed
```

**Purpose:** Makes robot move forward at specified speed

**Parameters:**
- `speed`: Motor speed (0-100), defaults to `BASE_SPEED` (55)

**What it does:**
1. Sends speed command to motor
2. Records current speed in state variable

**Usage examples:**
```python
self.forward()          # Move at BASE_SPEED (55)
self.forward(50)        # Move at SLOW_SPEED
self.forward(BASE_SPEED)  # Move at normal speed
```

### Stop

```python
def stop(self):
    self.motor.stop()
    self.current_speed = 0
```

**Purpose:** Stops the robot completely

**What it does:**
1. Calls motor's stop method (sets both direction pins LOW, PWM to 0)
2. Records speed as 0

### Steering

```python
def steer(self, angle):
    angle = max(-30, min(30, angle))
    servo_pos = SERVO_CENTER - angle
    self.servo_ctrl.move(SERVO_CHANNEL, int(servo_pos))
```

**Purpose:** Points wheels in specified direction

**How it works:**

**Step 1: Clamp angle**
```python
angle = max(-30, min(30, angle))
```
Limits angle to ±30° range:
- `angle = 50` → clamped to `30`
- `angle = -50` → clamped to `-30`
- `angle = 15` → unchanged

**Step 2: Convert to servo position**
```python
servo_pos = SERVO_CENTER - angle
```

**Formula explained:**
```
SERVO_CENTER = 92° (straight ahead)

Turn left (+15°):  servo_pos = 92 - 15 = 77°
Straight (0°):     servo_pos = 92 - 0 = 92°
Turn right (-15°): servo_pos = 92 - (-15) = 107°
```

**Why subtract?**
Servo mechanics: 
- Lower servo angles → wheels turn left
- Higher servo angles → wheels turn right
- This is opposite of intuitive steering angles

**Step 3: Move servo**
```python
self.servo_ctrl.move(SERVO_CHANNEL, int(servo_pos))
```
- Converts to integer (servos need whole numbers)
- Commands servo to move to calculated position

**Example scenarios:**
```python
self.steer(30)   # Max left: servo → 62°
self.steer(0)    # Straight: servo → 92°
self.steer(-30)  # Max right: servo → 122°
```

### Smooth Steering

```python
def steer_smooth(self, target_angle):
    target_angle = max(-30, min(30, target_angle))
    self.steering_history.append(target_angle)
    
    if len(self.steering_history) > 0:
        smooth_angle = sum(self.steering_history) / len(self.steering_history)
        self.steer(smooth_angle)
```

**Purpose:** Applies steering with smoothing to prevent jerky movements

**How smoothing works:**

**Step 1: Clamp and store**
```python
target_angle = max(-30, min(30, target_angle))
self.steering_history.append(target_angle)
```
- Clamps angle to valid range
- Adds to history deque (maxlen=3)

**Step 2: Calculate average**
```python
smooth_angle = sum(self.steering_history) / len(self.steering_history)
```

**Example:**
```python
# Initial state
steering_history = []

# First call: steer_smooth(20)
steering_history = [20]
smooth_angle = 20 / 1 = 20° → steer(20)

# Second call: steer_smooth(10)
steering_history = [20, 10]
smooth_angle = 30 / 2 = 15° → steer(15)

# Third call: steer_smooth(5)
steering_history = [20, 10, 5]
smooth_angle = 35 / 3 = 11.67° → steer(11.67)

# Fourth call: steer_smooth(-5)
steering_history = [10, 5, -5]  # Oldest (20) removed automatically
smooth_angle = 10 / 3 = 3.33° → steer(3.33)
```

**Why smooth steering?**
- Prevents sudden wheel movements
- Reduces mechanical stress on servo
- Makes navigation more stable
- Improves wall-following consistency

**Trade-off:**
- Slight delay in response (uses last 3 commands)
- More predictable behavior overall

### Center Steering

```python
def steer_center(self):
    self.servo_ctrl.move(SERVO_CHANNEL, SERVO_CENTER)
    self.steering_history.clear()
```

**Purpose:** Returns steering to center position for straight driving

**What it does:**
1. Moves servo directly to 92° (center)
2. Clears steering history (fresh start for smoothing)

**When used:**
- Before/after turns
- When stopping
- When resetting navigation state

---

## 13. Navigation System

### Estimate Corridor Width

```python
def estimate_corridor_width(self):
    left = self.distance_left()
    right = self.distance_right()
    
    if left and right:
        total_width = left + right
        self.corridor_width_history.append(total_width)
        
        if len(self.corridor_width_history) >= 10:
            avg_width = sum(self.corridor_width_history) / len(self.corridor_width_history)
            return "wide" if avg_width > 750 else "narrow"
    
    return "unknown"
```

**Purpose:** Determines if robot is in a wide or narrow corridor section

**Process:**

**Step 1: Get wall distances**
```python
left = self.distance_left()
right = self.distance_right()
```

**Step 2: Calculate total width**
```python
if left and right:
    total_width = left + right
    self.corridor_width_history.append(total_width)
```

**Example:**
```
Left wall: 400mm
Right wall: 450mm
Total width: 400 + 450 = 850mm
```

**Step 3: Average recent measurements**
```python
if len(self.corridor_width_history) >= 10:
    avg_width = sum(self.corridor_width_history) / len(self.corridor_width_history)
```

Waits for at least 10 measurements before making decision

**Step 4: Classify corridor**
```python
return "wide" if avg_width > 750 else "narrow"
```

**Classification:**
- **Wide corridor:** Average width > 750mm
  - Uses `TARGET_WALL_WIDE = 450mm` for wall following
- **Narrow corridor:** Average width ≤ 750mm
  - Uses `TARGET_WALL_NARROW = 250mm` for wall following

**Why different targets?**
- Wide corridors: Robot can maintain more distance from walls
- Narrow corridors: Robot must stay closer to walls to avoid hitting opposite side

**Return values:**
- `"wide"`: Corridor > 750mm
- `"narrow"`: Corridor ≤ 750mm
- `"unknown"`: Not enough data yet, or walls not detected

### Calculate Steering

This is the main navigation function with a priority system:

```python
def calculate_steering(self):
    """Improved wall following + Compass heading correction"""
    left_dist = self.distance_left()
    right_dist = self.distance_right()
    front_dist = self.distance_front()
    
    corridor_type = self.estimate_corridor_width()
    
    # Adjust target based on corridor width
    if corridor_type == "narrow":
        target_distance = TARGET_WALL_NARROW
    else:
        target_distance = TARGET_WALL_WIDE
```

**Setup:**
1. Gets current sensor readings (left, right, front)
2. Determines corridor type
3. Sets appropriate target distance:
   - Narrow: 250mm
   - Wide/Unknown: 450mm

#### Priority 1: Front Obstacle Avoidance

```python
    steering = 0
    heading_correction = self.calculate_heading_correction()
    
    # PRIORITY 1: Front obstacle avoidance
    if front_dist and front_dist < FRONT_TURN_THRESHOLD:
        # Front obstacle detected - prepare to turn
        if left_dist and right_dist:
            # Steer away from closer wall
            if right_dist < left_dist:
                steering = 25  # Steer left away from right wall
                print(f"  Front obstacle! Steering LEFT (R:{right_dist} < L:{left_dist})")
            else:
                steering = -25  # Steer right away from left wall
                print(f"  Front obstacle! Steering RIGHT (L:{left_dist} < R:{right_dist})")
        self.forward(SLOW_SPEED)
        return max(-30, min(30, steering))
```

**When triggered:** Front distance < 700mm

**Logic:**
1. Detects wall ahead
2. Checks which side wall is closer
3. Steers AWAY from the closer wall
4. Slows down to SLOW_SPEED (50)
5. Returns immediately (overrides all other navigation)

**Example:**
```
Front: 600mm (obstacle!)
Left: 300mm
Right: 450mm

Right < Left? No
→ Steer RIGHT (-25°) away from left wall
```

**Why this works:**
- Approaching a corner from left → right wall is farther → steer right
- Approaching a corner from right → left wall is farther → steer left
- Naturally positions robot for the turn

#### Priority 2: Right Wall Following

```python
    # PRIORITY 2: Right wall following (preferred)
    if right_dist and right_dist < 1000:  # Right wall detected within 1000mm
        error = target_distance - right_dist
        derivative = error - self.last_right_error
        self.last_right_error = error
        
        # Calculate steering to maintain target distance
        steering = error * KP_WALL + derivative * KD_WALL
```

**When triggered:** Right wall within 1000mm

**PD Control explanation:**

**Proportional term (P):**
```python
error = target_distance - right_dist
steering += error * KP_WALL
```

**Example (wide corridor, target = 450mm):**
```
Right distance: 300mm
Error: 450 - 300 = +150mm (too close)
P contribution: 150 * 0.04 = +6° (steer left to get farther)

Right distance: 600mm
Error: 450 - 600 = -150mm (too far)
P contribution: -150 * 0.04 = -6° (steer right to get closer)
```

**Derivative term (D):**
```python
derivative = error - self.last_right_error
steering += derivative * KD_WALL
```

**Purpose:** Dampens oscillations

**Example:**
```
Last error: +100mm
Current error: +150mm
Derivative: +150 - 100 = +50 (error increasing - moving toward wall fast)
D contribution: 50 * 0.025 = +1.25° (adds extra left steering to slow approach)

Last error: +150mm
Current error: +100mm
Derivative: +100 - 150 = -50 (error decreasing - moving away well)
D contribution: -50 * 0.025 = -1.25° (reduces left steering, don't overshoot)
```

**Speed adjustment based on proximity:**
```python
        # Speed adjustment based on proximity
        if right_dist < MIN_SAFE_DISTANCE:
            self.forward(SLOW_SPEED)
            steering *= 1.5  # More aggressive steering when too close
        elif right_dist < MIN_SAFE_DISTANCE * 1.5:
            self.forward(int(BASE_SPEED * 0.75))
        else:
            self.forward(BASE_SPEED)
```

**Speed zones:**
```
< 180mm:  SLOW_SPEED (50), steering × 1.5 (aggressive)
180-270mm: 75% speed (41), normal steering
> 270mm:  BASE_SPEED (55), normal steering
```

**Example:**
```
Right distance: 150mm (< 180mm)
→ Speed: 50
→ Base steering: +5°
→ Applied steering: +5 * 1.5 = +7.5° (more aggressive correction)
```

#### Priority 3: Left Wall Following

```python
    # PRIORITY 3: Left wall following (if no right wall)
    elif left_dist and left_dist < 1000:  # Left wall detected within 1000mm
        error = target_distance - left_dist
        derivative = error - self.last_left_error
        self.last_left_error = error
        
        # Calculate steering (negative because we want to steer right when too close to left)
        steering = -(error * KP_WALL + derivative * KD_WALL)
```

**When triggered:** No right wall, but left wall within 1000mm

**Why negative steering?**

```
Target: 450mm
Left distance: 300mm (too close)
Error: +150mm
Base correction: +150 * 0.04 = +6°
Applied steering: -(+6°) = -6° (steer RIGHT away from left wall)
```

**Sign conversion:**
- Right wall following: Positive error → steer left (positive)
- Left wall following: Positive error → steer right (negative)

**Same speed adjustment logic:**
```python
        if left_dist < MIN_SAFE_DISTANCE:
            self.forward(SLOW_SPEED)
            steering *= 1.5
        elif left_dist < MIN_SAFE_DISTANCE * 1.5:
            self.forward(int(BASE_SPEED * 0.75))
        else:
            self.forward(BASE_SPEED)
```

#### Priority 4: No Walls Detected

```python
    # PRIORITY 4: No walls detected - go straight
    else:
        steering = 0
        self.forward(BASE_SPEED)
        self.last_left_error = 0
        self.last_right_error = 0
```

**When triggered:** No walls within 1000mm on either side

**Action:**
- Steering: 0° (straight)
- Speed: BASE_SPEED (55)
- Resets error history (fresh start when walls reappear)

#### Compass Correction Overlay

```python
    # Add compass correction (smaller weight so it doesn't override wall avoidance)
    steering += heading_correction * 0.5
    
    return max(-30, min(30, steering))
```

**Final step:**
1. Adds compass-based heading correction
2. Multiplied by 0.5 (reduced weight)
3. Clamps final result to ±30°

**Example:**
```
Wall-following steering: +10°
Heading correction: -4°
Combined: 10 + (-4 * 0.5) = 10 - 2 = +8°
Final steering: +8°
```

**Why 0.5 weight?**
- Wall avoidance is higher priority
- Compass provides gentle corrections
- Prevents compass from overriding safety behaviors

---

## 14. 90-Degree Turn Execution

```python
def execute_90_degree_turn(self, direction):
    """Execute a compass-guided 90-degree turn"""
    print(f"\n  Executing 90° turn {direction.upper()}")
    self.navigation_mode = "turning"
    
    pre_turn_target = self.target_heading
```

**Setup:**
- Prints turn direction
- Changes mode to "turning" (disables wall-following)
- Saves current target heading

### Compass Failure Fallback

```python
    # Safety check: if no compass heading, use dead reckoning
    if pre_turn_target is None:
        print("  WARNING: No compass heading! Using dead reckoning...")
        self.steer_center()
        self.forward(SLOW_SPEED)
        time.sleep(0.3)  # Move forward
        
        # Execute turn by time
        self.forward(TURN_SPEED)
        if direction == 'right':
            self.steer(-PRE_TURN_STEER_ANGLE)
        else:
            self.steer(PRE_TURN_STEER_ANGLE)
        
        time.sleep(0.8)  # Turn for fixed time
        
        self.steer_center()
        self.forward(BASE_SPEED)
        time.sleep(0.3)
        self.navigation_mode = "wall_follow"
        return
```

**Dead reckoning mode** (if compass unavailable):

1. **Move forward:** 0.3 seconds straight
2. **Turn:** Steer ±30° for 0.8 seconds
3. **Continue:** Center steering and drive forward 0.3 seconds
4. **Resume:** Return to wall-following mode

**Why needed?**
If compass fails, robot can still complete turns (though less accurately).

### Calculate New Target Heading

```python
    if direction == 'right':
        new_target = normalize_angle(pre_turn_target + 90)
    else:
        new_target = normalize_angle(pre_turn_target - 90)
    
    print(f"  Current target: {pre_turn_target:.0f}° → New target: {new_target:.0f}°")
```

**Heading calculation:**

**Right turn:**
```python
new_target = normalize_angle(pre_turn_target + 90)
```

**Examples:**
```
Current: 0° → Right turn → 90°
Current: 90° → Right turn → 180°
Current: 270° → Right turn → 360° → normalizes to 0°
```

**Left turn:**
```python
new_target = normalize_angle(pre_turn_target - 90)
```

**Examples:**
```
Current: 90° → Left turn → 0°
Current: 0° → Left turn → -90° → normalizes to 270°
```

### Three-Phase Turn Sequence

#### Phase 1: Move Forward

```python
    # Move forward to clear obstacle
    print("  Moving forward...")
    self.steer_center()
    self.forward(SLOW_SPEED)
    time.sleep(0.1)
```

**Purpose:** Moves slightly forward to clear any front obstacles

**Duration:** 0.1 seconds at SLOW_SPEED (50)

**Distance traveled:** ~2-3cm (depending on actual speed calibration)

#### Phase 2: Execute Turn

```python
    # Execute turn
    print(f"  Turning to {new_target:.0f}°...")
    self.forward(TURN_SPEED)
    
    if direction == 'right':
        self.steer(-PRE_TURN_STEER_ANGLE)
    else:
        self.steer(PRE_TURN_STEER_ANGLE)
```

**Steering setup:**
- Right turn: Steer -30° (turn wheels right)
- Left turn: Steer +30° (turn wheels left)
- Speed: TURN_SPEED (50)

#### Phase 3: Compass-Guided Completion

```python
    turn_start_time = time.time()
    max_turn_time = 0.8
    
    while time.time() - turn_start_time < max_turn_time:
        self.update_lidar()
        current = self.heading()
        
        if current is not None:
            error = abs(angle_difference(new_target, current))
            
            if error < HEADING_TOLERANCE:
                print(f"  Turn complete! Heading: {current:.0f}° (error: {error:.1f}°)")
                break
            
            if error < 15:
                self.forward(SLOW_SPEED)
                if direction == 'right':
                    self.steer(-20)
                else:
                    self.steer(20)
        
        time.sleep(0.02)
```

**Turn monitoring loop:**

1. **Timeout protection:** Max 0.8 seconds
2. **Continuous LiDAR updates:** Maintains sensor data
3. **Check heading:** Compare current vs target
4. **Exit condition:** Error < 10° (HEADING_TOLERANCE)
5. **Fine adjustment:** When error < 15°, reduce steering to ±20°

**Example:**
```
Target: 90°
Current: 45° → Error: 45° → Keep turning at ±30°
Current: 75° → Error: 15° → Still turning at ±30°
Current: 82° → Error: 8° → COMPLETE! Exit loop
```

#### Finalization

```python
    self.target_heading = new_target
    
    self.steer_center()
    self.forward(BASE_SPEED)
    time.sleep(0.5)
    
    self.navigation_mode = "wall_follow"
    print(f"  Now facing {self.target_heading:.0f}° - continuing")
```

**Cleanup:**
1. Updates target_heading to new value
2. Centers steering
3. Resumes normal speed for 0.5 seconds
4. Returns to wall-following mode
5. Prints confirmation

---

## 15. Main Mission Loop

### Mission Initialization

```python
def run_mission(self):
    print("\n" + "="*70)
    print(" WRO MISSION: NEW TURNING STRATEGY")
    print(" 1. Detect line with A3 sensor")
    print(" 2. Move forward until side > 1500mm")
    print(" 3. Turn to that side and remember direction")
    print(" 4. Repeat for all subsequent lines")
    print("="*70 + "\n")
    
    print("Calibrating compass...")
    for _ in range(20):
        self.update_lidar()
        time.sleep(0.05)
    self.set_initial_heading()
```

**Startup sequence:**
1. Prints mission strategy
2. Calibrates compass (20 readings over 1 second)
3. Sets initial heading
4. Prepares to start

### Main Loop Structure

```python
    try:
        print("Starting mission...")
        self.forward(BASE_SPEED)
        last_print = time.time()
        
        while True:
            self.update_lidar()
```

**Loop basics:**
- Starts moving forward immediately
- Updates LiDAR every iteration (~50Hz)
- Continues until stop conditions met

### Stop Conditions (After 12 Turns)

```python
            # ========================================================
            # CHECK STOP CONDITIONS (after 12 turns completed)
            # ========================================================
            if self.turn_count >= 12 and not self.waiting_for_clearance:
                current_heading = self.heading()
                front_dist = self.distance_front()
                
                if current_heading is not None and front_dist is not None:
                    heading_error = abs(angle_difference(self.target_heading, current_heading))
                    
                    if heading_error <= HEADING_TOLERANCE and front_dist < 1800:
                        print(f"\n{'='*70}")
                        print(" ✓ STOP CONDITIONS MET!")
                        print(f" Heading error: {heading_error:.1f}° (≤10°) ✓")
                        print(f" Front distance: {front_dist}mm (<1800mm) ✓")
                        print(f"{'='*70}")
                        break
```

**Two conditions must be met:**
1. **Heading error ≤ 10°:** Robot facing starting direction
2. **Front distance < 1800mm:** Robot near starting wall

**Why both?**
- Heading alone: Might stop mid-lap
- Distance alone: Might stop at wrong corner
- Combined: Confirms return to start position

### Phase 1: Line Detection

```python
            if not self.waiting_for_clearance and self.turn_count < 12:
                current_time = time.time()
                if not hasattr(self, 'last_line_detect_time_ignore'):
                    self.last_line_detect_time_ignore = 0
                
                LINE_IGNORE_TIME = 3.0
                
                if current_time - self.last_line_detect_time_ignore > LINE_IGNORE_TIME:
                    if self.detect_line():
                        self.last_line_detect_time_ignore = current_time
                        self.turn_count += 1
                        lap = (self.turn_count - 1) // 4 + 1
                        section = (self.turn_count - 1) % 4 + 1
                        
                        print(f"\n{'='*70}")
                        print(f" TURN #{self.turn_count} - LINE DETECTED")
                        print(f" LAP: {lap}/3 | SECTION: {section}/4")
                        print(f"{'='*70}")
```

**Line detection with debouncing:**

1. **Ignore timer:** Prevents detecting same line multiple times
2. **3-second cooldown:** After detecting a line, ignores lines for 3 seconds
3. **Turn counter:** Increments on each detection
4. **Progress calculation:**
   - Lap = (turn_count - 1) ÷ 4 + 1
   - Section = (turn_count - 1) mod 4 + 1

**Examples:**
```
Turn 1: Lap 1, Section 1
Turn 4: Lap 1, Section 4
Turn 5: Lap 2, Section 1
Turn 12: Lap 3, Section 4
```
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

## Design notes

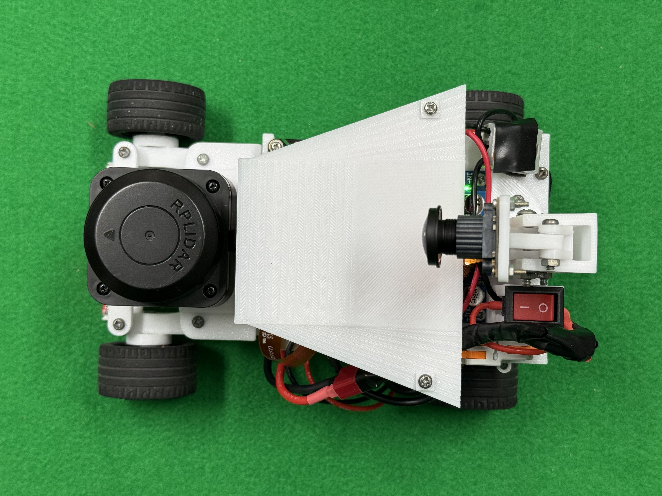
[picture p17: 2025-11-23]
Robot-Photos/Top Side.jpg

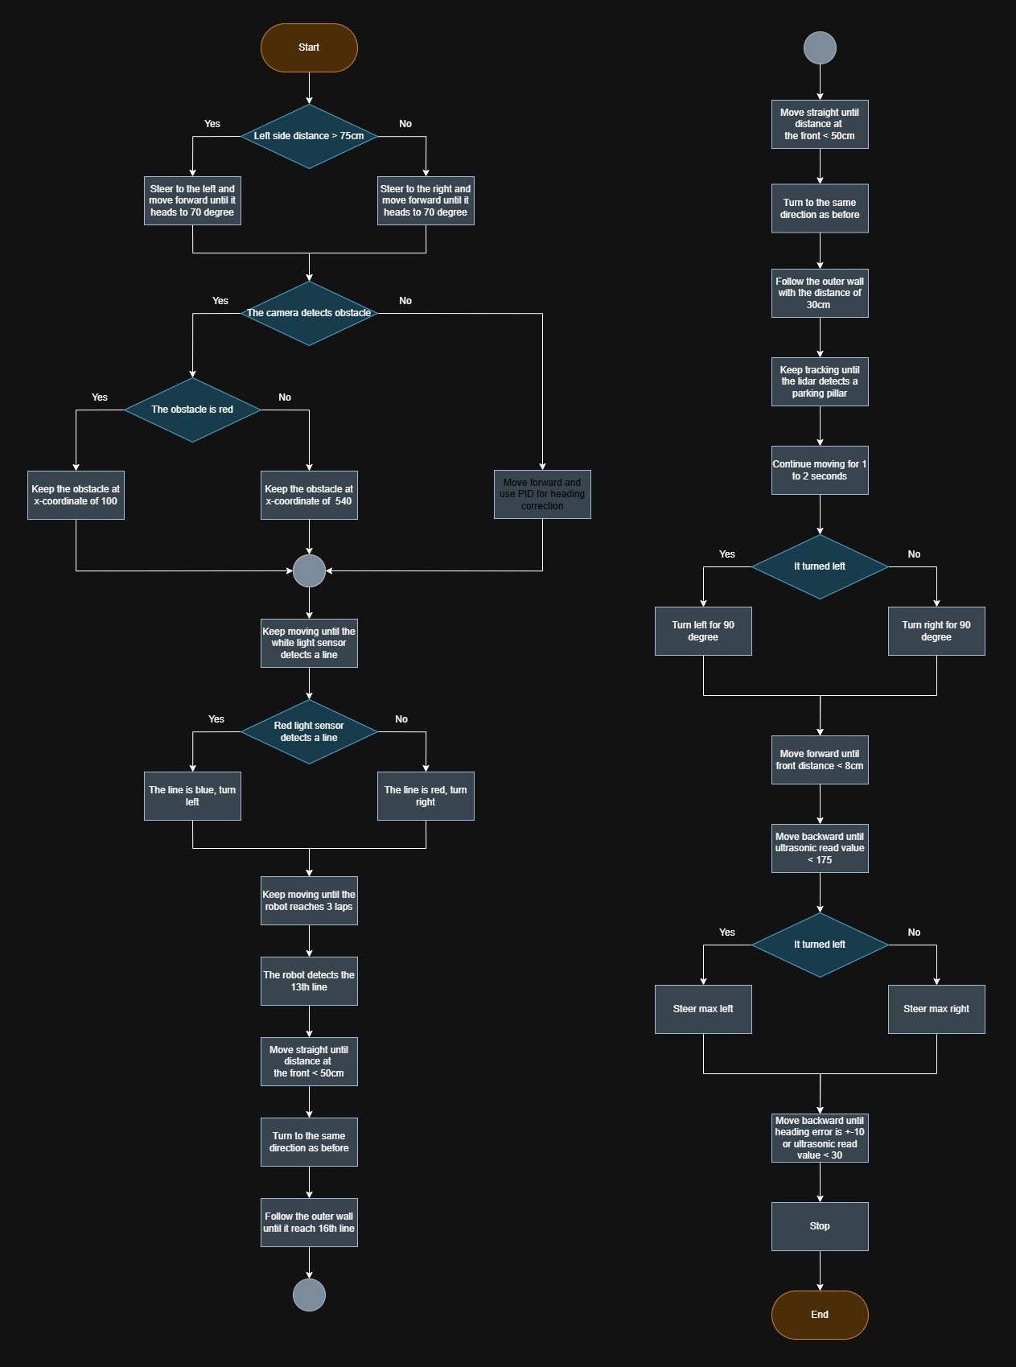
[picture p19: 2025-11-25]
FlowChart/Obstacle_Challenge.jpg

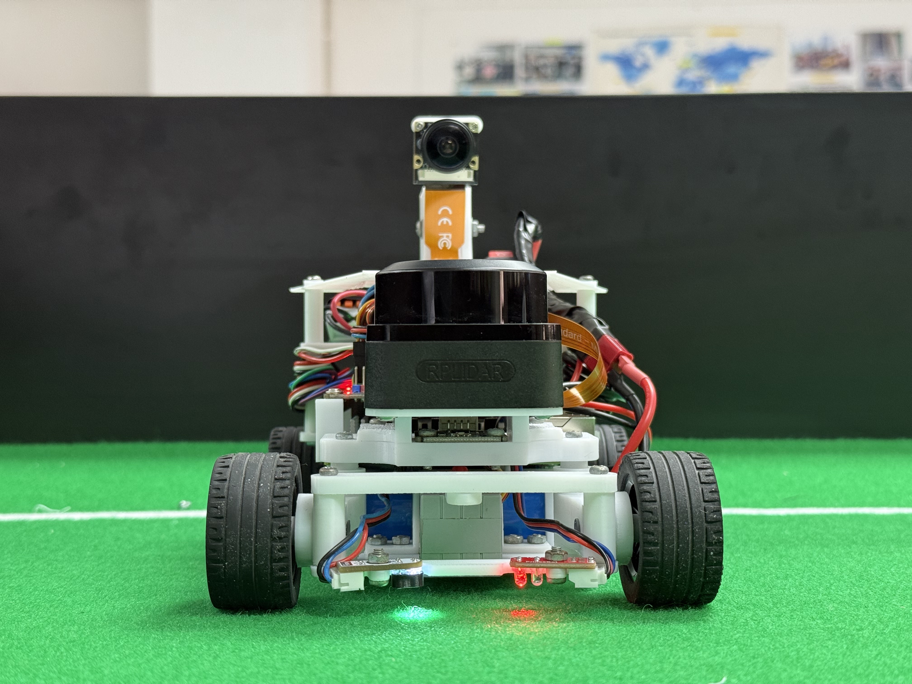
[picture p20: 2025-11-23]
Robot-Photos/Front Side.jpg

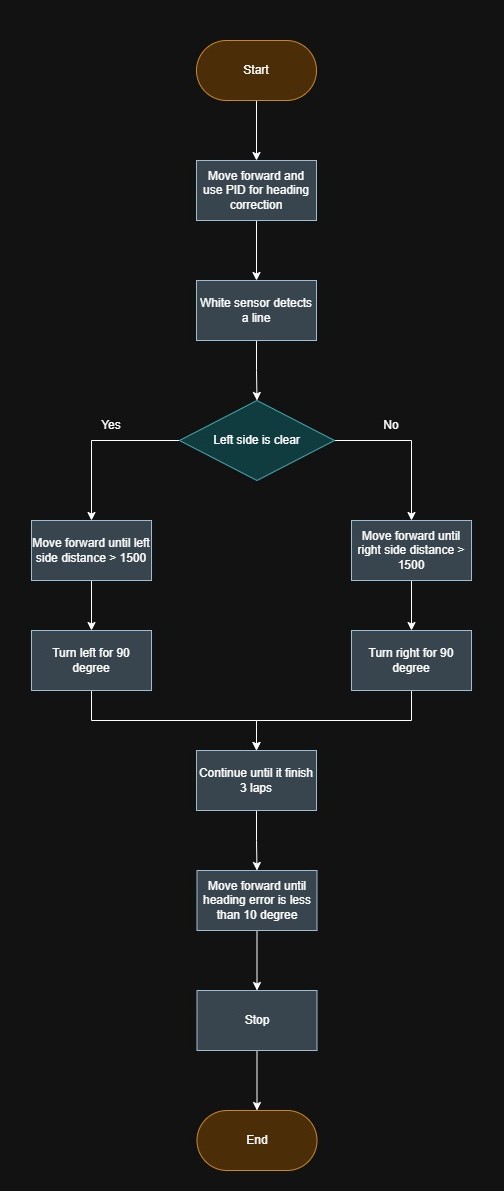
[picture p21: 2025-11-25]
FlowChart/Open_Challenge.jpg

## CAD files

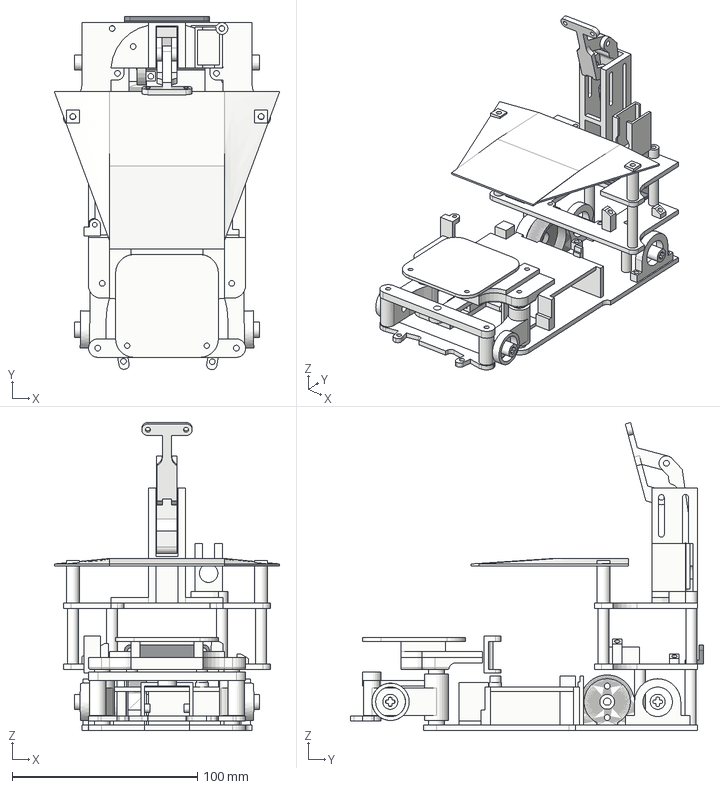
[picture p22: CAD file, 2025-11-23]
3DModels/Complete Parts Set(.step)/Complete Parts Set.step
121.8 x 191.0 x 166.5 mm
part_object_id_1
gear adapter
FE001_1
CAM holder
CAM arm

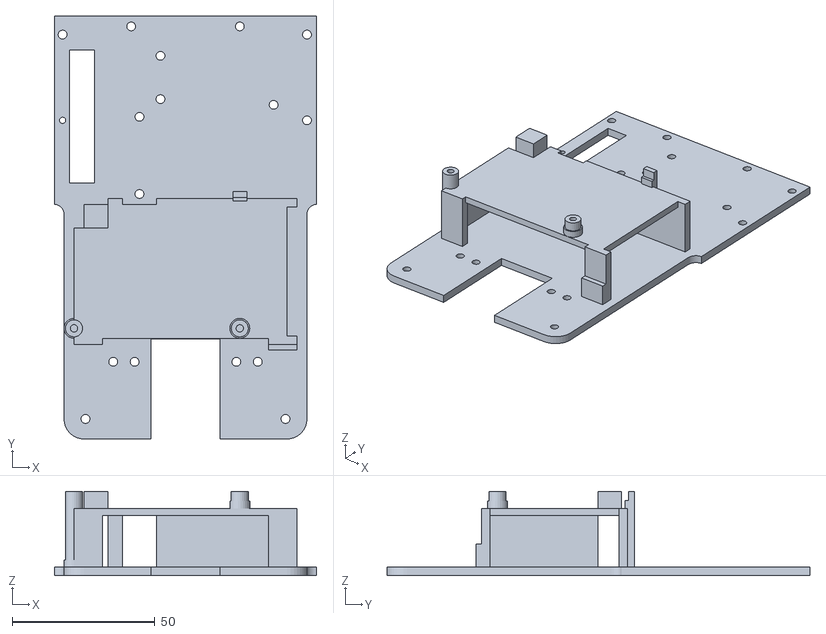
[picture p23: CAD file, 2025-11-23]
3DModels/Main Base.stl
91.8 x 148.0 x 29.4

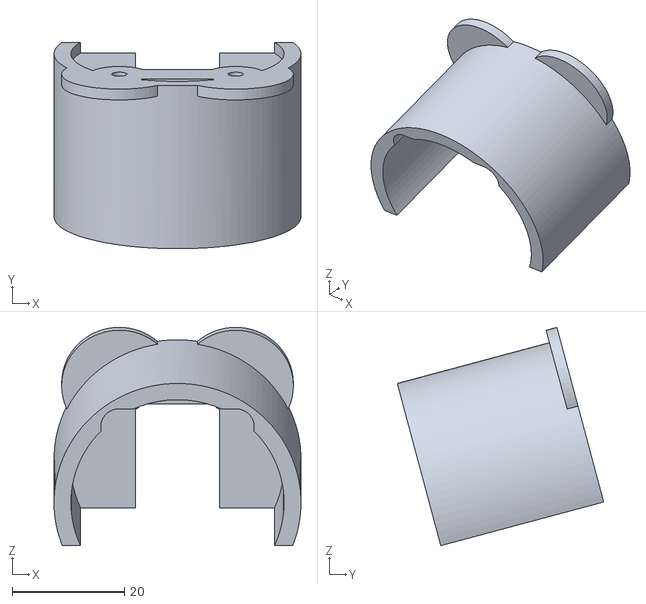
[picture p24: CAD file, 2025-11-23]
3DModels/Camera Light Shield.stl
43.9 x 36.7 x 38.8

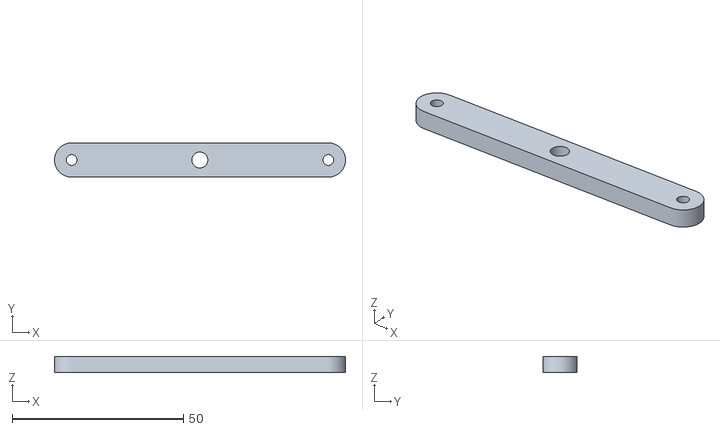
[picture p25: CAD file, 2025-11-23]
3DModels/Top Steering Mount.stl
84.9 x 10.0 x 4.75

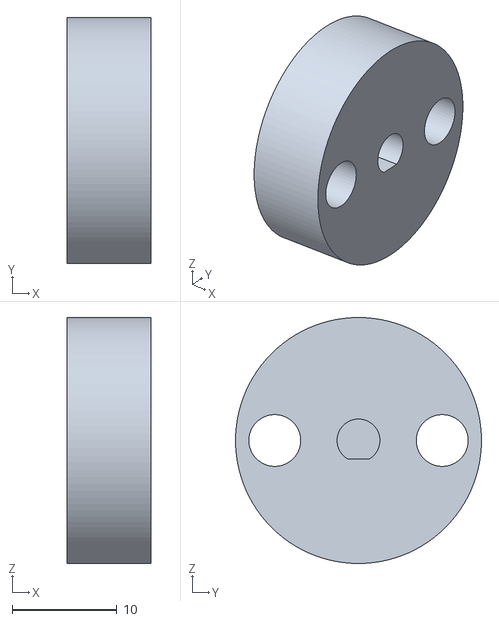
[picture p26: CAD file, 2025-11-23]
3DModels/Gear Adapter.stl
8.07 x 23.5 x 23.5

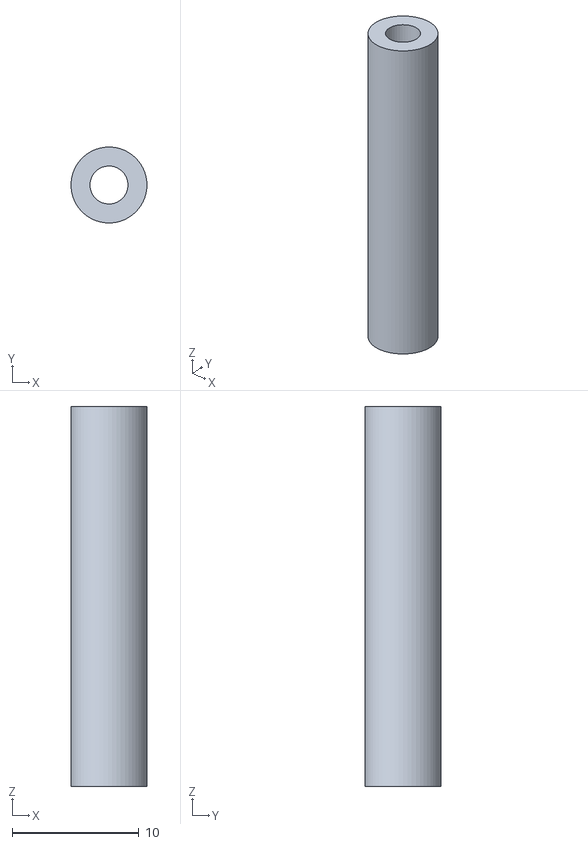
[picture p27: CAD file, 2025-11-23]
3DModels/Mounting Standoff 30mm x7.stl
6.00 x 6.00 x 30.0

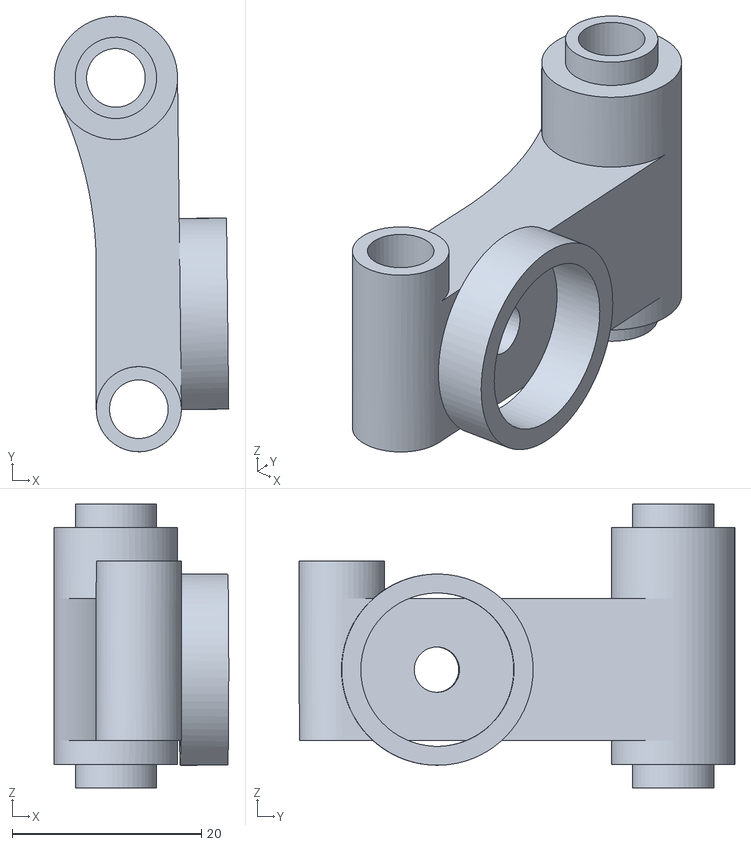
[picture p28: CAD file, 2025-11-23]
3DModels/Left Steering Arm.stl
18.4 x 46.0 x 30.0

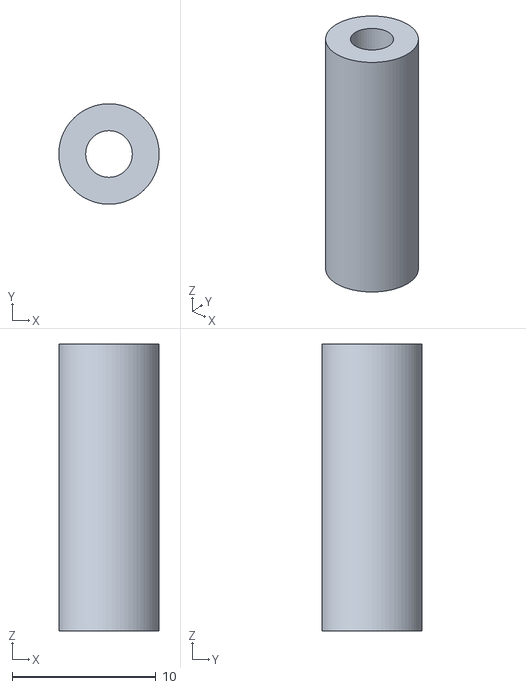
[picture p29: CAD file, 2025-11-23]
3DModels/Through-Hole Spacer 20mm x2.stl
7.00 x 6.99 x 20.0

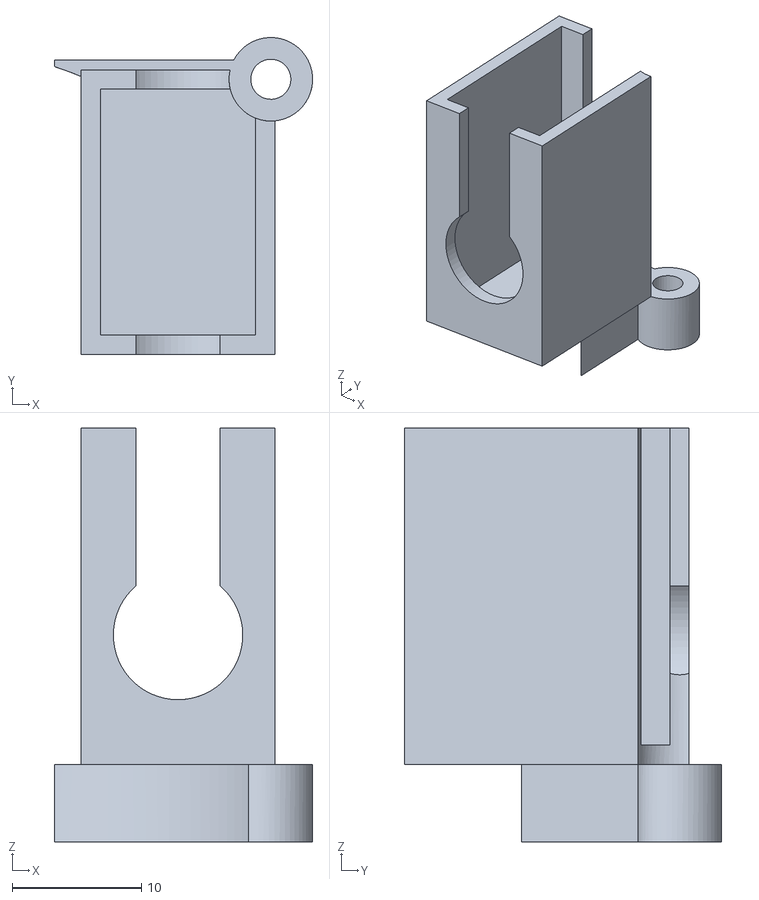
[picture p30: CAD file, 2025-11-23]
3DModels/Switch Box.stl
20.0 x 24.5 x 32.0

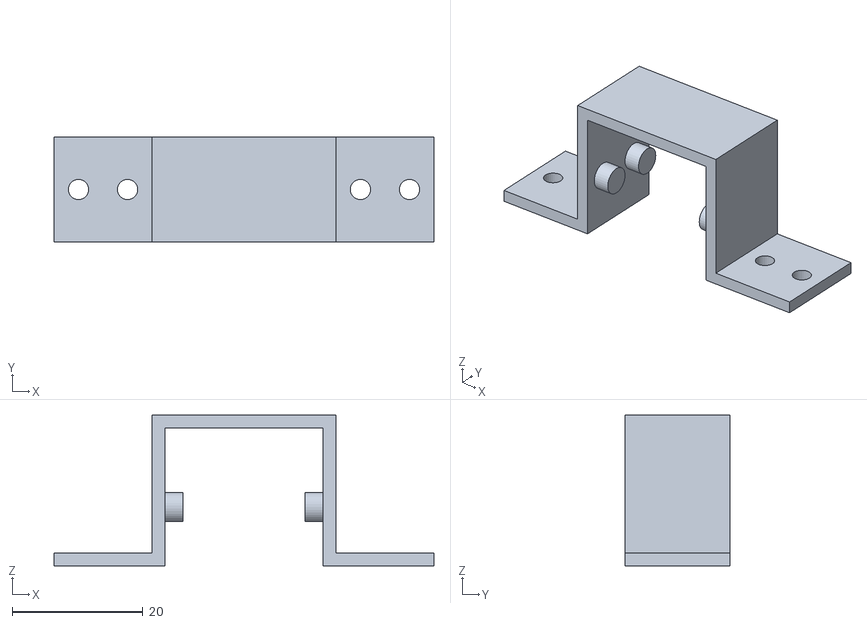
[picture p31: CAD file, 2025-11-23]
3DModels/Servo Bracket.stl
58.1 x 16.0 x 23.0

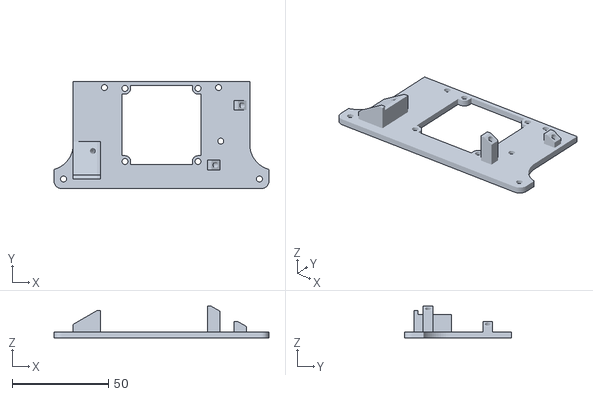
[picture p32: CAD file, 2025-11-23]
3DModels/Support Base 2.1.stl
111.8 x 55.8 x 16.4

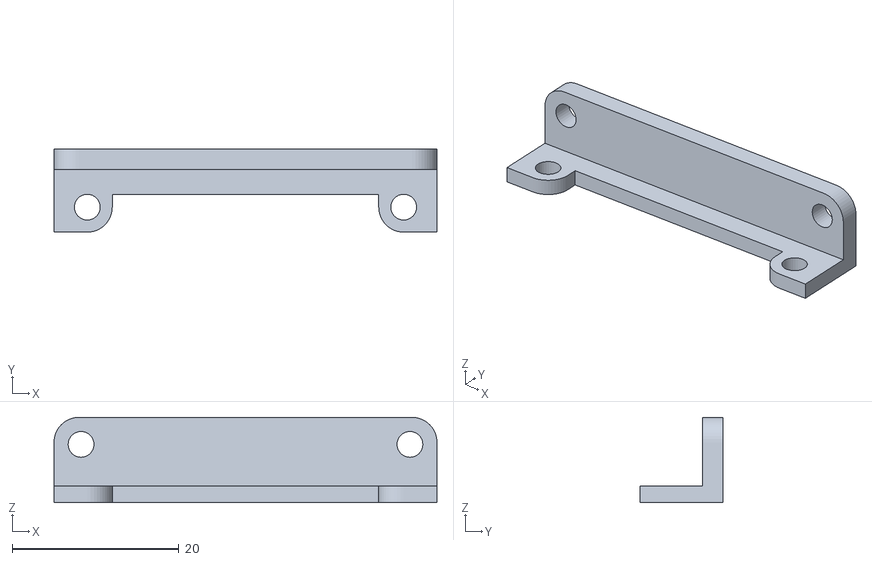
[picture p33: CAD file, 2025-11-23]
3DModels/Ultrasonic Sensor Mount.stl
46.0 x 10.0 x 10.2

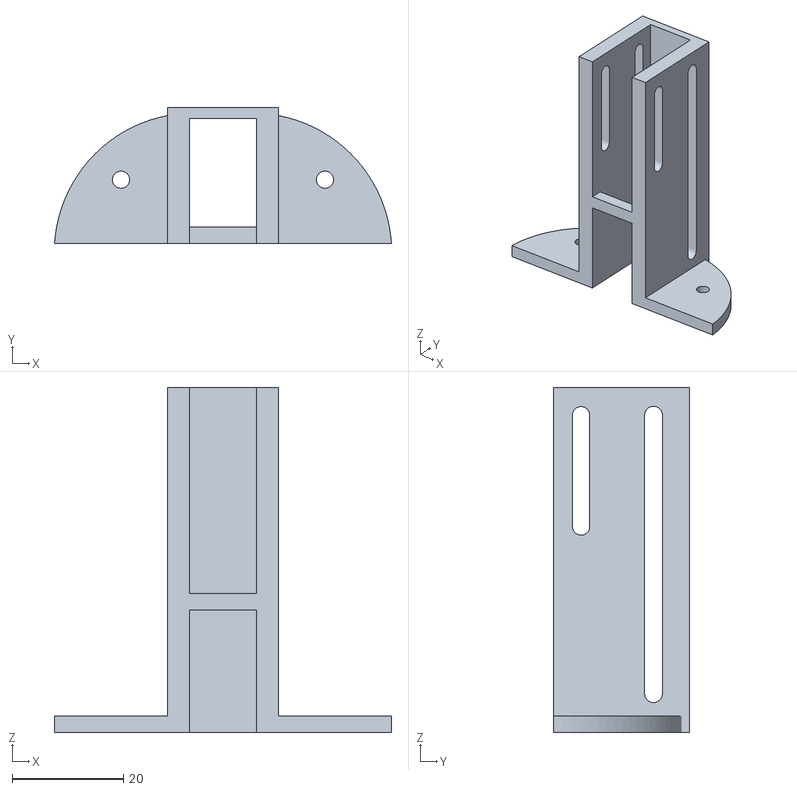
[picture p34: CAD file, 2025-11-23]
3DModels/Camera Adjustment Column.stl
60.5 x 24.5 x 62.0

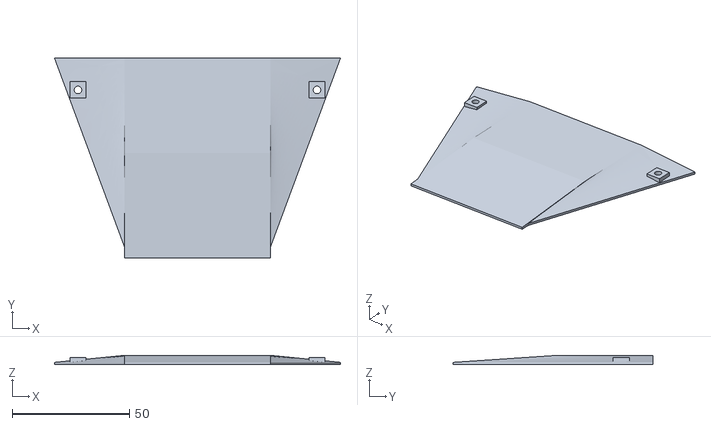
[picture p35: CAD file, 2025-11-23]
3DModels/Camera Shield Plate.stl
121.8 x 85.0 x 4.00

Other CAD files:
3DModels/Right Steering Arm.stl
3DModels/Axle Sleeve Adapter(For Front Wheel) x2.stl
3DModels/Right Bearing Mount.stl
3DModels/Support Base 2.2.stl
3DModels/Angle Adjustment Link.stl
3DModels/Board Support Pillar (M2.5-M3).stl
3DModels/Bottom Steering Mount.stl
3DModels/Camera Height Adjustment Link.stl
3DModels/Left Axle Sleeve Adapter(For Rear Wheel).stl
3DModels/Left Bearing Mount.stl
3DModels/Lidar Mount.stl
3DModels/Middle Bearing Mount.stl
3DModels/Motor Mount.stl
3DModels/Right Axle Sleeve Adapter(For Rear Wheel).stl
3DModels/Steering Linkage Arm.stl
3DModels/Support Base 1.stl

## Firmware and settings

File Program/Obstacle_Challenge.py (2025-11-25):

import sys
sys.path.append("/home/Book_Pi/DFRobot_RaspberryPi_Expansion_Board")
from DFRobot_RaspberryPi_Expansion_Board import DFRobot_Expansion_Board_IIC as Board
from DFRobot_RaspberryPi_Expansion_Board import DFRobot_Expansion_Board_Servo as Servo

import serial
import time
from collections import deque
import RPi.GPIO as GPIO

try:
    import board as board_pins
    import busio
    import adafruit_bno055
    COMPASS_AVAILABLE = True
except ImportError as e:
    COMPASS_AVAILABLE = False
    board_pins = None
    busio = None
    adafruit_bno055 = None

import math
import atexit
import cv2 as cv
from picamera2 import Picamera2
import numpy as np
import statistics

MOTOR_IN1 = 6
MOTOR_IN2 = 7
MOTOR_ENA = 5

SERVO_CHANNEL = 0
SERVO_CENTER = 94
MAX_TURN_ANGLE = 60

LIDAR_PORT = '/dev/ttyAMA0'
LIDAR_BAUD = 460800

CAMERA_WIDTH = 640
CAMERA_HEIGHT = 480
CROP_TOP = 220
CROP_BOTTOM = 380

SHOW_CAMERA = False

RED_RANGES = [(np.array([173, 144, 61]), np.array([179, 255, 165]))]
GREEN_RANGES = [(np.array([53, 90, 79]), np.array([68, 198, 150]))]

ULTRA = 0
LIGHT_SENSOR_RED = 2
LIGHT_SENSOR_WHITE = 3
RED_THRESHOLD = 2000
WHITE_THRESHOLD = 3200

FRONT_MIN = 355
FRONT_MAX = 5
LEFT_ZONE_MIN = 250
LEFT_ZONE_MAX = 290
RIGHT_ZONE_MIN = 70
RIGHT_ZONE_MAX = 110

LIDAR_MIN_QUALITY = 5
LIDAR_MIN_DISTANCE = 30
LIDAR_MAX_DISTANCE = 4000
LIDAR_OUTLIER_THRESHOLD = 0.3

HEADING_TOLERANCE = 10
HEADING_KP = 0.5

BASE_SPEED = 50
SLOW_SPEED = 40
TURN_SPEED = 40
PARKING_SPEED = 50

TARGET_WALL_WIDE = 450
TARGET_WALL_NARROW = 180
MIN_SAFE_DISTANCE = 150
KP_WALL = 0.015
KD_WALL = 0.025

INNER_WALL_TARGET = 140
OUTER_WALL_TARGET = 140
KP_PARKING = 0.06
KD_PARKING = 0.06

OBSTACLE_MIN_AREA = 275
OBSTACLE_Y_MIN = 35
OBSTACLE_Y_MAX = 250

RED_TARGET = 100
GREEN_TARGET = 500

OBSTACLE_KP = 0.08
OBSTACLE_KD = 0.012

EMERGENCY_AREA_THRESHOLD = 18000
EMERGENCY_Y_THRESHOLD = 240

IGNORE_SIDE_OBSTACLES_TIME = 0.8
OBSTACLE_X_MIN = 50 
OBSTACLE_X_MAX = 590
LINE_IGNORE_TIME = 2.0
FIRST_LINE_SAMPLE_TIME = 0.1

OBSTACLE_PASSED_Y_THRESHOLD = 35
OBSTACLE_PASSED_TIME = 0.8

def clamp(value, min_val, max_val):
    return max(min_val, min(max_val, value))

def normalize_angle(angle):
    while angle < 0:
        angle += 360
    while angle >= 360:
        angle -= 360
    return angle

def angle_difference(target, current):
    diff = target - current
    if diff > 180:
        diff -= 360
    elif diff < -180:
        diff += 360
    return diff

def correct_lidar_angle(lidar_angle, heading_offset):
    corrected = lidar_angle - heading_offset
    return normalize_angle(corrected)

class SimpleMotor:
    def __init__(self, in1, in2, ena):
        self.in1, self.in2, self.ena = in1, in2, ena
        GPIO.setmode(GPIO.BCM)
        GPIO.setwarnings(False)
        GPIO.setup(self.in1, GPIO.OUT)
        GPIO.setup(self.in2, GPIO.OUT)
        GPIO.setup(self.ena, GPIO.OUT)
        self.pwm = GPIO.PWM(self.ena, 1000)
        self.pwm.start(0)
    
    def set_speed(self, speed):
        speed = max(-100, min(100, speed))
        if speed > 0:
            GPIO.output(self.in1, GPIO.HIGH)
            GPIO.output(self.in2, GPIO.LOW)
            self.pwm.ChangeDutyCycle(abs(speed))
        elif speed < 0:
            GPIO.output(self.in1, GPIO.LOW)
            GPIO.output(self.in2, GPIO.HIGH)
            self.pwm.ChangeDutyCycle(abs(speed))
        else:
            self.stop()
    
    def stop(self):
        GPIO.output(self.in1, GPIO.LOW)
        GPIO.output(self.in2, GPIO.LOW)
        self.pwm.ChangeDutyCycle(0)
    
    def cleanup(self):
        self.stop()
        self.pwm.stop()

def create_multi_range_mask(hsv: np.ndarray, color_ranges):
    if not color_ranges:
        return np.zeros(hsv.shape[:2], dtype=np.uint8)
    
    combined_mask = cv.inRange(hsv, color_ranges[0][0], color_ranges[0][1])
    
    for lower, upper in color_ranges[1:]:
        mask = cv.inRange(hsv, lower, upper)
        combined_mask = cv.bitwise_or(combined_mask, mask)
    
    return combined_mask

class Picamera2Detector:
    def __init__(self, show_display=True):
        self.show_display = show_display
        try:
            self.picam2 = Picamera2()
            config = self.picam2.create_preview_configuration(
                main={"size": (CAMERA_WIDTH, CAMERA_HEIGHT), "format": "BGR888"}
            )
            self.picam2.start()
            time.sleep(1)
        except Exception as e:
            raise
    
    def detect_obstacles(self):
        try:
            frame = self.picam2.capture_array()
            
            if frame is None or frame.size == 0:
                return []
            
            if len(frame.shape) != 3 or frame.shape[0] < CROP_BOTTOM or frame.shape[1] < CAMERA_WIDTH:
                return []
            
            cropped_frame = frame[CROP_TOP:CROP_BOTTOM, :]
            
            if cropped_frame.size == 0:
                return []
            
            hsv_frame = cv.cvtColor(cropped_frame, cv.COLOR_RGB2HSV)
            hsv_frame = cv.GaussianBlur(hsv_frame, (5, 5), 0)
            
            detected_obstacles = []
            
            if self.show_display:
                display_frame = cropped_frame.copy()
                cv.line(display_frame, (RED_TARGET, 0), (RED_TARGET, 200), (0, 0, 255), 2)
                cv.line(display_frame, (GREEN_TARGET, 0), (GREEN_TARGET, 200), (0, 255, 0), 2)
                cv.rectangle(display_frame, (0, OBSTACLE_Y_MIN), (CAMERA_WIDTH, OBSTACLE_Y_MAX), 
                           (255, 255, 0), 1)
            
            color_configs = {
                'red': RED_RANGES,
                'green': GREEN_RANGES
            }
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
